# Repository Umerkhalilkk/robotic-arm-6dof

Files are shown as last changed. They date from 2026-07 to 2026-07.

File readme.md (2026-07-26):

# Robotic Arm (6 DOF)

A robotic arm controlled through a smaller, hand-built master arm. Potentiometers on the master arm sense joint position, and a microcontroller maps those readings to servo positions on the main arm, so moving a joint on the small arm moves the corresponding joint on the large arm in real time.

## Photos

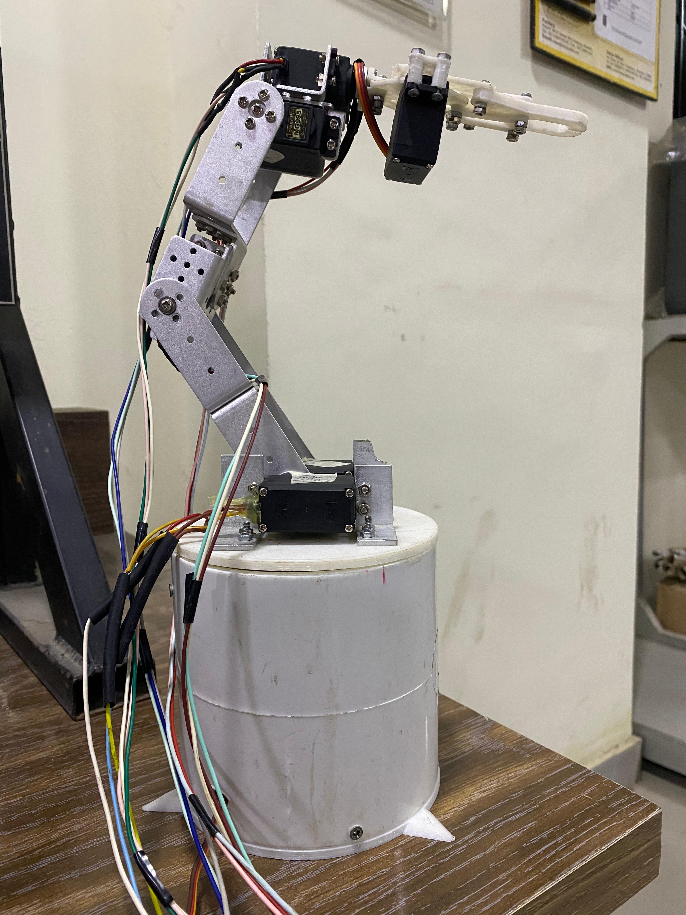
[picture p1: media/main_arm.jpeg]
Main robotic arm
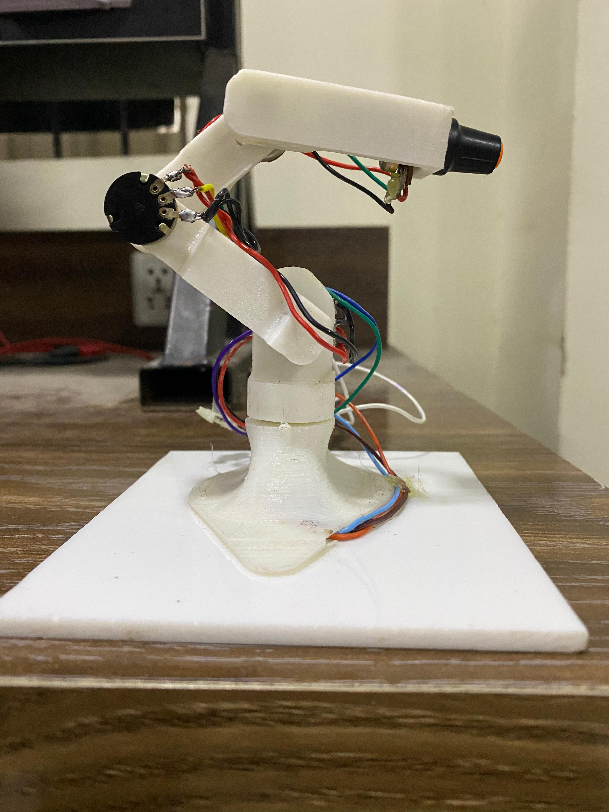
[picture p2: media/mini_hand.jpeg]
Master arm (mini hand)
 

*Left: the main 6 DOF robotic arm. Right: the master arm used to control it.*

## Team

- [Muhammad Aqib Shabbir](https://github.com/maqibshabbir)
- Muhammad Umer
- Areesh e Mustafa

## Overview

The system consists of two physical arms and one control board.

**Main arm** — the arm being controlled. The base was built around a custom PCB, with the base structure (bottom, middle, top) and body designed and modeled by the team in SolidWorks. The gripper mechanism uses an existing open-source design, adapted and 3D printed in PLA. The arm is driven by seven servo motors.

**Master arm (mini hand)** — the input device, also designed and built by the team. It uses five potentiometers to represent five of the main arm's joints, plus one push button to control the gripper (open/close).

**Control board** — an Arduino Uno reads the potentiometer and button states, maps them to servo angles, and drives the main arm's servos accordingly. A custom PCB was designed and etched at home to host the electronics, and the system is powered from a computer power supply rather than batteries.

## How it works

```
Potentiometer / Button (master arm) → Arduino Uno → Servo Motors (main arm)
```

1. Each potentiometer on the master arm outputs an analog voltage corresponding to its joint's position.
2. The Arduino reads these values and maps them from the 0–1023 ADC range to a 0–180 degree servo range.
3. The mapped angle is written to the matching servo on the main arm.
4. The push button toggles the gripper servo between open and closed positions.
5. Joint values are also printed to the Serial Monitor for live monitoring.

### Smoothing servo jitter

During testing, the servos exhibited jerky, unstable movement. An oscilloscope was used to inspect the PWM control signal directly, which helped identify the source of the instability and guided the changes made to smooth out motion. This hardware-level verification is what separated debugging this build from a purely code-side fix.

## Repository structure

```
cad/
  main_arm/
    arm-base/              Base structure — bottom, middle, top, and main parts
    arm-body/               Arm body and servo/horn components
    arm-full-assembly/      Full main arm assembly
    arm-gripper/            Gripper design (third-party, see Credits) and assembly
  mini_hand/
    arm-full-assembly/      Full master arm assembly
    arm-full-body/          Master arm links and base

docs/
  robotic_arm_6dof_technical_report.pdf   Full project report

firmware/
  arm_controller.ino        Arduino firmware

media/
  main_arm.jpeg              Photo of the completed main arm
  mini_hand.jpeg              Photo of the completed master arm

models/
  main_arm.stl               Interactive 3D model of the main arm
  mini_arm.stl                Interactive 3D model of the master arm

pcb/
  arm_pcb_print.pdf          PCB layout used for home etching
  pcb_front.jpg               Photo of the built PCB, front
  pcb_back.jpg                Photo of the built PCB, back
```

## 3D Models

Both arms can be viewed and rotated directly in the browser using GitHub's built-in 3D viewer — no software download required. Click a link below, then click-drag to rotate and scroll to zoom.

- [Main Arm — main_arm.stl](models/main_arm.stl)
- [Mini Hand — mini_arm.stl](models/mini_arm.stl)

## Hardware

- Microcontroller: Arduino Uno
- 7x servo motor (main arm joints and gripper)
- 5x potentiometer (master arm joint sensing)
- 1x push button (gripper control)
- Custom PCB (etched at home from the layout in `pcb/arm_pcb_print.pdf`)
- Power: computer power supply unit
- 3D printed gripper (PLA)
- Base: custom PCB-integrated structure, with bottom/middle/top sections modeled in SolidWorks

## Software tools used

- SolidWorks — CAD modeling of the base, body, and master arm
- Arduino IDE — firmware
- Proteus — schematic and PCB design assistance
- Oscilloscope — signal-level debugging of servo control lines

## Getting started

1. Open `firmware/arm_controller.ino` in the Arduino IDE.
2. Wire the potentiometers and servos according to the pin definitions at the top of the code.
3. Upload the firmware to the Arduino Uno.
4. Power the board using a regulated supply matching the servo current requirements.
5. Open the Serial Monitor (9600 baud) to view live joint values while testing.

## Results

The arm reliably mirrored the master arm's movements, with the gripper responding correctly to the push button. Oscilloscope-guided debugging resolved early jitter issues, producing smooth, consistent motion. Full details, results, and discussion are documented in the project report: [`docs/robotic_arm_6dof_technical_report.pdf`](docs/robotic_arm_6dof_technical_report.pdf)

## Credits

- Gripper CAD design: third-party design, adapted for this build (source to be added)
- PCB layout assistance: Engr. Zaryab Qazi

## License

This project is released under the MIT License. See [`LICENSE`](LICENSE) for details.

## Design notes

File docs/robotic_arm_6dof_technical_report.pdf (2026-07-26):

# ENGINEERING WORKSHOP

## Project Title:

## Robotic Arm (6 DOF)

## Submitted to:

## Zaryab Qazi

## Submitted by:

## - Muhammad Aqib Shabbir

## - Muhammad Umer

## - Areesh e Mustafa

## Table of Contents

### 1. ABSTRACT:

This project presents the design and development of a 6 Degrees of Freedom (DOF)

robotic arm controlled by a miniature robotic arm with integrated potentiometers for

position feedback. The system is designed to simulate and replicate the movements

of the main robotic arm based on the inputs received from the mini arm, enabling

precise control and manipulation. The main robotic arm is modeled in SolidWorks,

allowing for detailed mechanical design and motion analysis. Potentiometers

attached to the mini arm measure joint angles and provide real-time feedback to a

microcontroller, which processes the data to control the movement of the main arm.

The project integrates hardware components, including motors, sensors, and

microcontrollers, with software algorithms for calculations and motion control. The

result is a functional, interactive robotic system capable of replicating the movements

of the mini arm, offering valuable insights into the fields of robotics, control systems, and automation. This design can serve as a foundation for more advanced

applications in robotic manipulation and automation tasks.

## 2. INTRODUCTION:

Robotic arms have become a cornerstone of automation and precision tasks across

various industries, including manufacturing, healthcare, and research. The ability to

control the position and movement of these arms with high accuracy and flexibility

is crucial for achieving complex operations. This project focuses on the design and

development of a 6 Degrees of Freedom (DOF) robotic arm that is controlled using

a miniature robotic arm equipped with potentiometers for precise joint position

feedback. The mini arm acts as a control interface, where the movement of its joints

is sensed and translated into corresponding actions in the main robotic arm.

The main robotic arm, designed and modeled using SolidWorks, consists of six

independently controlled joints, allowing for a wide range of motion and flexibility.

Each joint is connected to a motor, with feedback from potentiometers attached to

the mini arm’s joints providing real-time positional data. This data is processed by a

microcontroller to calculate the necessary movements for the main arm, ensuring

accurate replication of the mini arm’s movements.

This project combines mechanical engineering, control systems, and electronics to

create an interactive robotic arm. The control system, using a microcontroller and

potentiometer feedback, maps the motion of a mini arm to the main arm, enabling

precise manipulation. The goal is to demonstrate a system that mimics the movement

of the smaller arm with high accuracy, offering insights for future robotics research

and applications. This design can be adapted for various robotic tasks, enhancing the

control and manipulation of multi-jointed robotic systems.

## 3. SOFTWARE TOOLS

The following software tools are commonly used in the design, and control of robotic

systems like the one described in this

- SolidWorks: Used for 3D modeling and design of the robotic arm, including

the main arm, joints, and mini arm. SolidWorks also enables motion simulations and interference checks. CAD design, motion simulation,

assembly design, kinematic analysis.

- Arduino IDE: The primary environment for programming the

microcontroller (such as Arduino or ESP32) that controls the robotic arm.

C/C++ programming, serial communication, support for sensors and

actuators, integration with external libraries for controlling motors and

reading potentiometer values.

- Proteus: Proteus supports simulation of microcontrollers, so you can write

the control code (e.g., Arduino code) in the Arduino IDE, then upload it to

the Proteus simulation for testing. PCB design, schematic capture, and layout.

The PCB design for this project was created with the assistance of Engr.

Zaryab Quazi, who provided valuable expertise in the design and layout of

the circuit board.

## 4. FLOW CHART

## 5. CODE

#include <Servo.h>

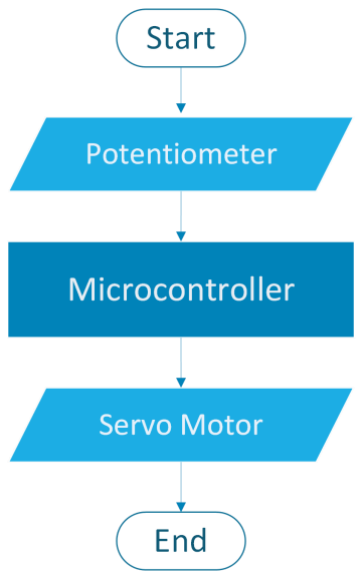
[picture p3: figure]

Servo servo1; const int
servo1PotPin =A0; const
int servo1Pin = 7; int
servo1Value; Servo servo2; const int servo2PotPin =A1; const int servo2Pin = 6;
int servo2Value; Servo
servo3; const int
servo3PotPin =A2; const int servo3Pin = 5; int
servo3Value; Servo servo4; const int servo4PotPin =A3; const int servo4Pin = 3;
int servo4Value; Servo
servo5; const int
servo5PotPin =A4; const int servo5Pin = 4; int
servo5Value;
Servo servo6;
const int servo6buttonPin =13; const int servo6Pin = 2; int pushButton; void setup() { Serial.begin(9600);
servo1.attach(servo1Pin);
servo2.attach(servo2Pin);
servo3.attach(servo3Pin);
servo4.attach(servo4Pin);
servo5.attach(servo5Pin);
servo6.attach(servo6Pin);
} void loop() { | servo1Value =
analogRead(servo1PotPin); | servo1Value =
map(servo1Value, 1023, 0, 0, 180); servo1.write(servo1Value); Serial.print(servo1Value);
servo2Value = analogRead(servo2PotPin); servo2Value = map(servo2Value, 0, 1023, 0, 180); servo2.write(servo2Value);
Serial.print(" ");Serial.print(servo2Value); servo3Value = analogRead(servo3PotPin); servo3Value = map(servo3Value, 0, 1023, 0, 180); servo3.write(servo3Value);
Serial.print(" ");Serial.print(servo3Value); servo4Value = analogRead(servo4PotPin); servo4Value = map(servo4Value, 0, 1023, 0, 180); servo4.write(servo4Value);
Serial.print(" ");Serial.print(servo4Value); servo5Value = analogRead(servo5PotPin); servo5Value = map(servo5Value, 0, 1023, 0, 180); servo5.write(servo5Value);

Serial.print(" ");Serial.print(servo5Value);

pushButton=digitalRead(servo6buttonPin); if(pushButton==LOW)
{
servo6.write(0);
Serial.print(" ");Serial.print("Close"); }
else
{
servo6.write(45);
Serial.print(" ");Serial.println("Open"); }
delay(5);
}

## 6. WORKING

The robotic arm operates through the input of six control elements: five

potentiometers and a push button. These control elements are used to monitor and

adjust the position of the arm's joints. Each potentiometer is connected to a specific

joint on the mini robotic arm and acts as a position sensor, determining the angle of

the joint. When the mini arm moves, the corresponding potentiometer detects the

change in joint position by varying its resistance. This change in resistance is

converted into an analog voltage, which is then sent to the microcontroller for

processing.

The microcontroller reads the analog values from the potentiometers via the Analog

Read Pins. Since the potentiometer’s output ranges from 0 to 1023, corresponding to

the full range of motion (0 to 180 degrees) of the servo motors, the microcontroller

maps these values to a servo-friendly range using the map() function. This function

adjusts the range of values from (0-1023) into a 0–180-degree range, which is the

operational range for standard servos.

Once the potentiometer values are mapped to a degree range, the microcontroller

sends the corresponding signals to the servo motors, which adjust the position of the

joints in the main robotic arm.

The robotic arm includes a push button that controls the sixth servo, which might

represent a gripper or similar mechanism. This push button is connected to a digital

input pin of the microcontroller. The button has two possible states: pressed (LOW)

or released (HIGH). When the button is pressed (LOW state), the sixth servo moves

to the "closed" position, which could mean the gripper closes. When the button is

released (HIGH state), the sixth servo moves to the "open" position, causing the

gripper to open. This allows for manual control of a specific function, such as

gripping or releasing objects.

The serial monitor displays the potentiometer values in real-time, providing feedback

on each joint's angle as the potentiometers are adjusted. This helps the user track the

arm's movements and troubleshoot if necessary. A 5-millisecond delay in the loop()

function ensures smooth and controlled motion, preventing the servos from moving

too quickly and causing instability.

In summary, the system reads potentiometer inputs to control the servo motors of the

main robotic arm, with the push button controlling a sixth servo (e.g., a gripper). The

serial monitor provides real-time feedback, offering an intuitive way to control the

robotic arm based on the mini arm's movements.

## 7. RESULT AND DISCUSSIONS

The 6-DOF robotic arm operated as expected, with the potentiometers providing

accurate control over the arm's movements. Each joint's position was directly linked

to its corresponding potentiometer, with smooth and responsive servo motion. The

push button effectively controlled the 6th servo, allowing for simple gripper

functionality, toggling between "open" and "closed" positions.

The 5-millisecond delay in the loop() function ensured smooth motion and prevented

jittery movements by slowing down the servo response. The real-time feedback on

the serial monitor helped track the arm’s performance, providing useful data for

troubleshooting.

Overall, the system performed well with precise and synchronized movement

between the mini and main robotic arms. Potential improvements include fine-tuning

the servo precision, adding advanced control algorithms, and incorporating

additional sensors for enhanced functionality.

## 8. CONCLUSION

The 6-DOF robotic arm, controlled by potentiometers and a push button, successfully

demonstrated the ability to replicate the motion of a mini robotic arm. The system operated smoothly, with the potentiometers providing precise control over each joint,

and the push button enabling simple control of the 6th servo (e.g., for gripper

function). The use of a delay ensured stable movement, and the serial monitor

provided real-time feedback for monitoring and debugging.

This project highlights the potential for using basic sensors and simple control

systems to operate complex robotic systems. Future improvements could involve

refining the control algorithms and adding more sensors for enhanced precision and

functionality. Overall, the project serves as a solid foundation for further exploration

and development in robotic control systems.

## 9. PROJECT SUMMARY

This project involves the design and implementation of a 6-DOF robotic arm

controlled by a mini arm equipped with potentiometers and a push button. The

potentiometers detect the angle of each joint on the mini arm, and their corresponding

values are sent to a microcontroller, which processes these inputs to control the

movement of the main robotic arm. The push button controls a 6th servo, such as a

gripper, allowing for simple open/close functionality. The system operates smoothly,

with real-time feedback displayed on the serial monitor for monitoring the arm's

movements. A delay is included in the control loop to ensure stable motion and avoid

erratic servo movements. This project demonstrates the use of basic sensors and

control systems to create a functional and responsive robotic arm, offering a

foundation for further development in robotic automation.

### 10. REFERENCES

Arduino. (n.d.). Arduino Documentation. Retrieved December 26, 2024, from

https://www.arduino.cc/

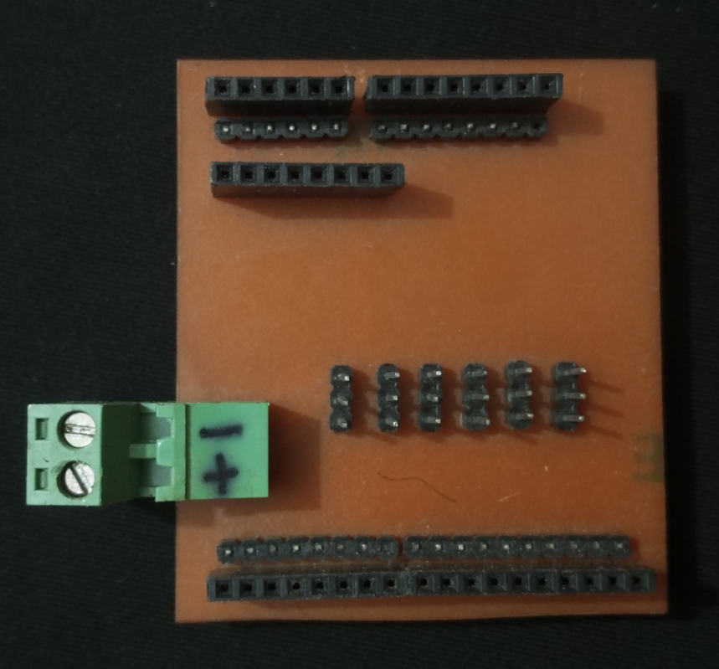
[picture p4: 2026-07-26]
pcb/pcb_front.jpg.jpeg

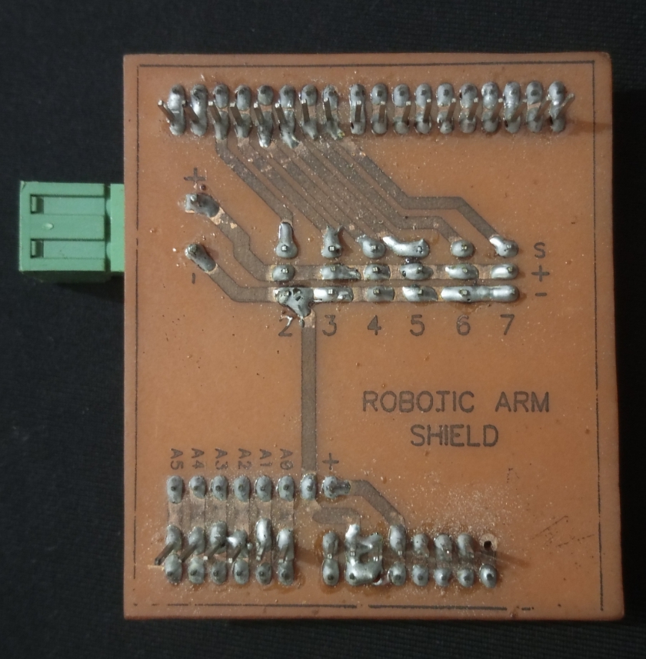
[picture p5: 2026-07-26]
pcb/pcb_back.jpg.jpeg

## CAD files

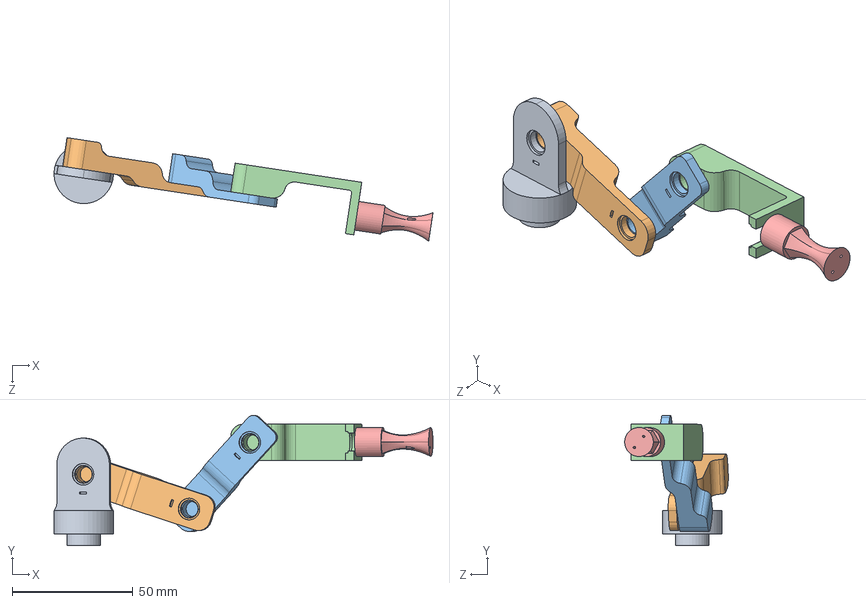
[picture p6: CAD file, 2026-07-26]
cad/mini_hand/arm-full-assembly/Assem1.SLDASM
156.8 x 53.9 x 42.9 mm
base
link 1
link 2
link 3
rotatory link

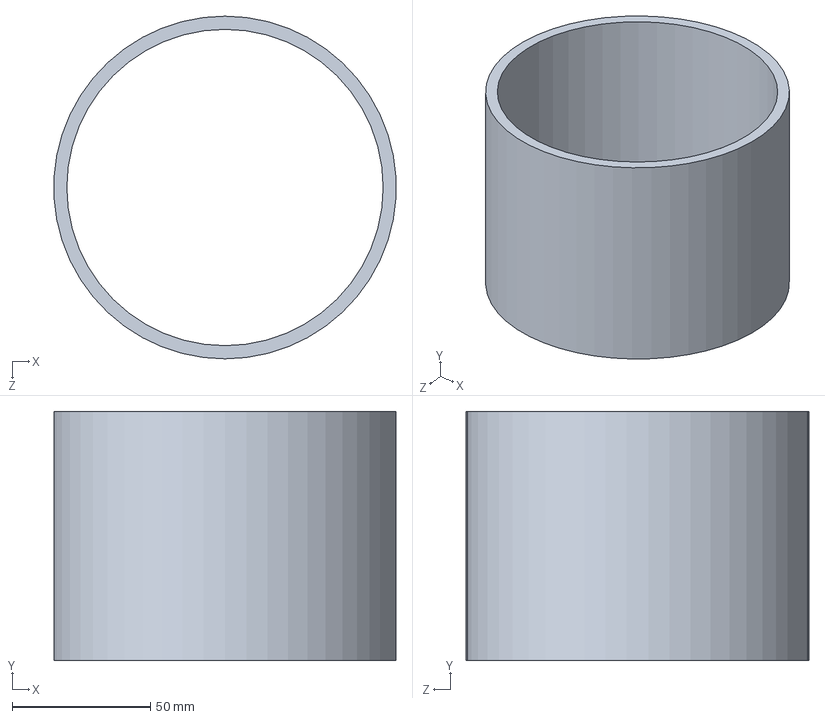
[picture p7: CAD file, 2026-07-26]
cad/main_arm/arm-base/main.SLDPRT
123.6 x 90.0 x 123.8 mm

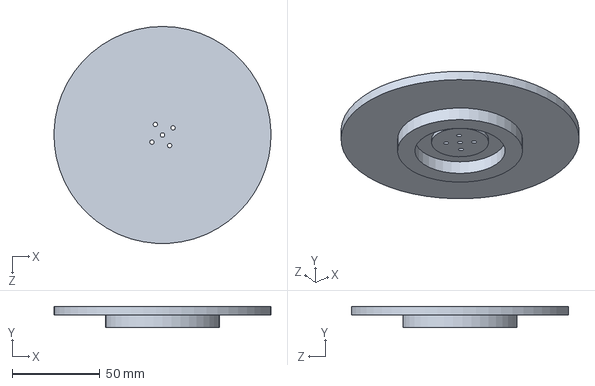
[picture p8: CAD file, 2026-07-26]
cad/main_arm/arm-base/top.SLDPRT
123.8 x 12.0 x 123.8 mm

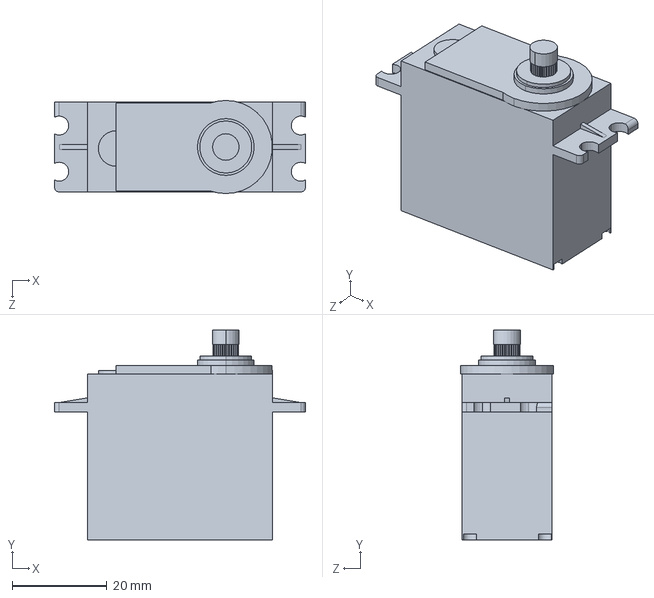
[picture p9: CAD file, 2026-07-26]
cad/main_arm/arm-body/macro-servo2.SLDPRT
53.0 x 44.3 x 19.7 mm

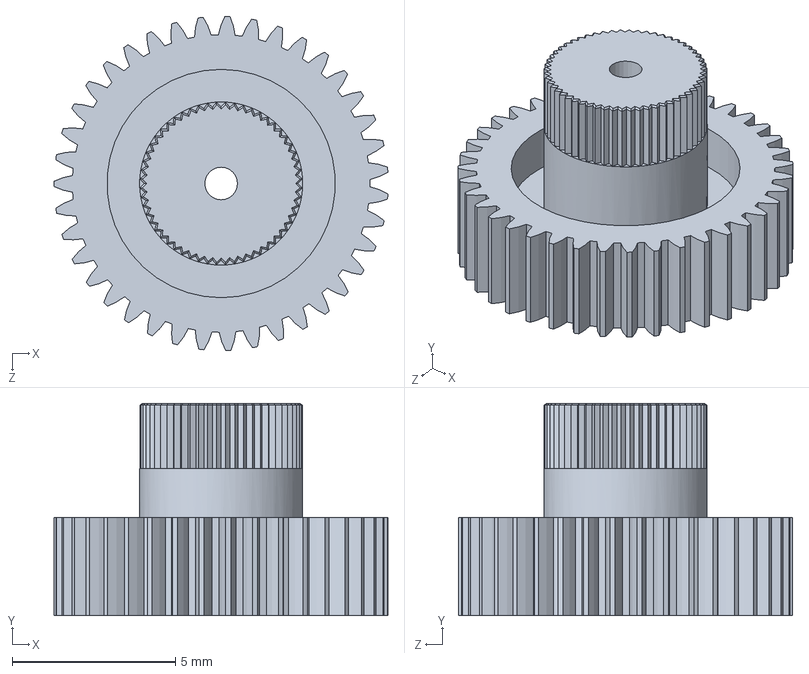
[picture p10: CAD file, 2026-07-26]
cad/main_arm/arm-gripper/4.SLDPRT
10.2 x 6.50 x 10.2 mm

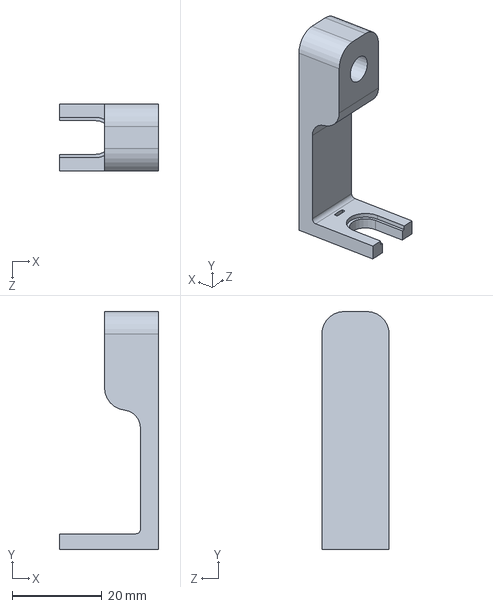
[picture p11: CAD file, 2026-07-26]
cad/mini_hand/arm-full-body/link 3.SLDPRT
22.0 x 53.0 x 15.0 mm

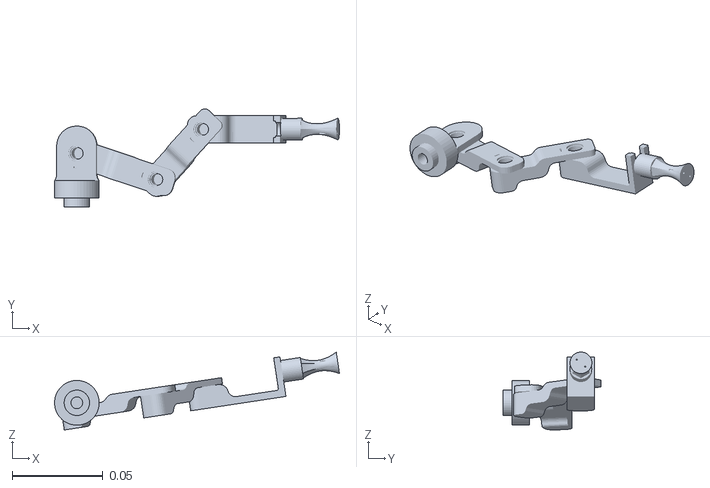
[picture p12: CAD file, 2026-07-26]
models/mini_arm.stl
0.157 x 0.0539 x 0.0429

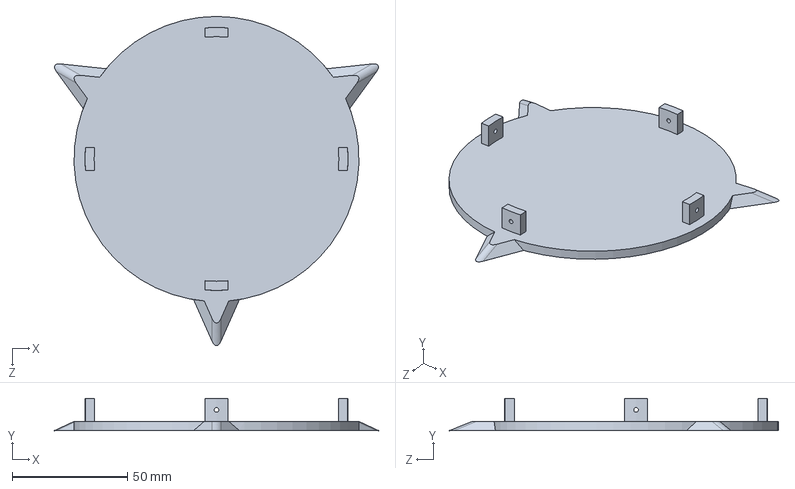
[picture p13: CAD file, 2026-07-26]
cad/main_arm/arm-base/bottom.SLDPRT
140.8 x 14.0 x 143.0 mm

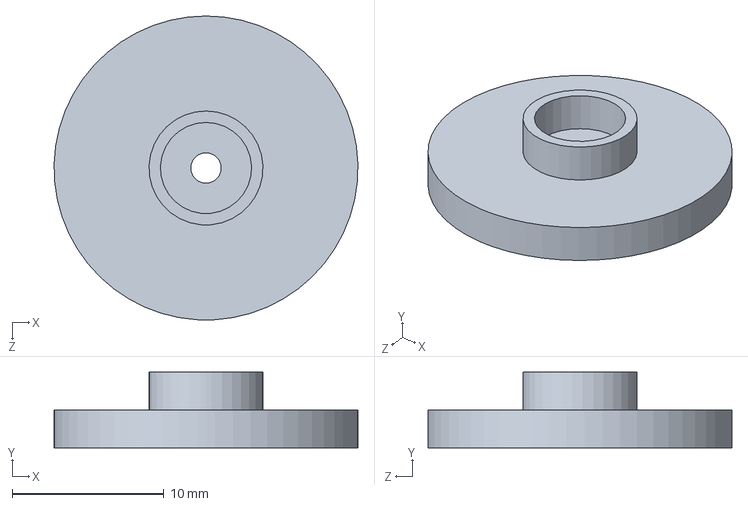
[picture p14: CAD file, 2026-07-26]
cad/main_arm/arm-body/servo horn.SLDPRT
20.0 x 5.00 x 20.0 mm

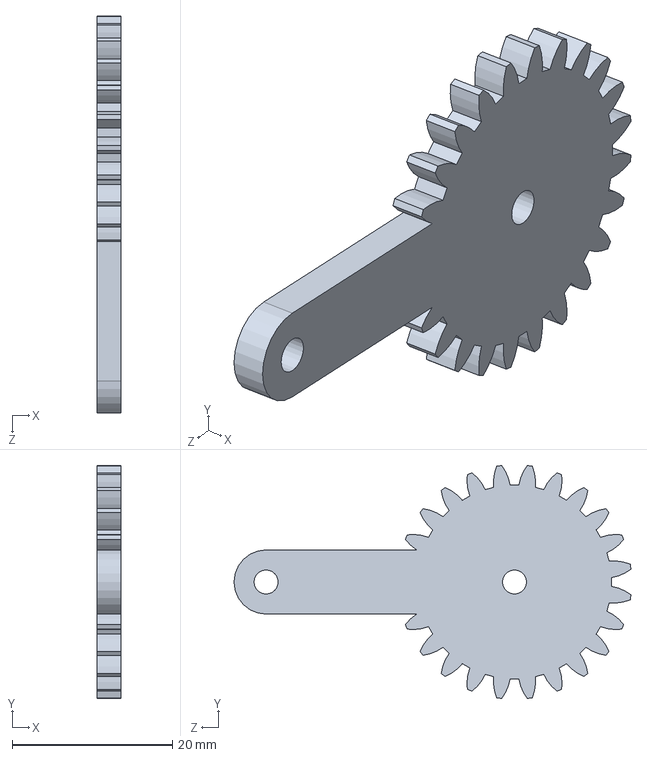
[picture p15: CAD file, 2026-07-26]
cad/main_arm/arm-gripper/4.1.SLDPRT
3.00 x 29.1 x 49.5 mm

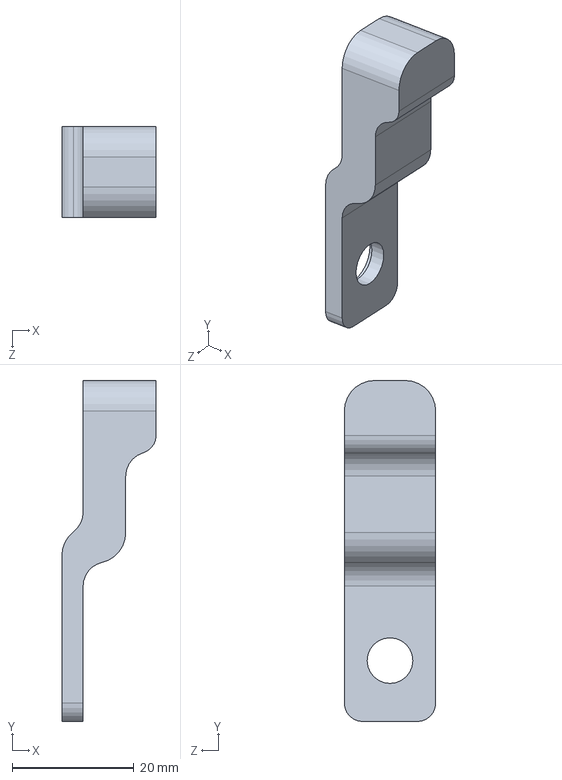
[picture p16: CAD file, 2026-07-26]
cad/mini_hand/arm-full-body/link 2.SLDPRT
15.5 x 56.0 x 15.0 mm

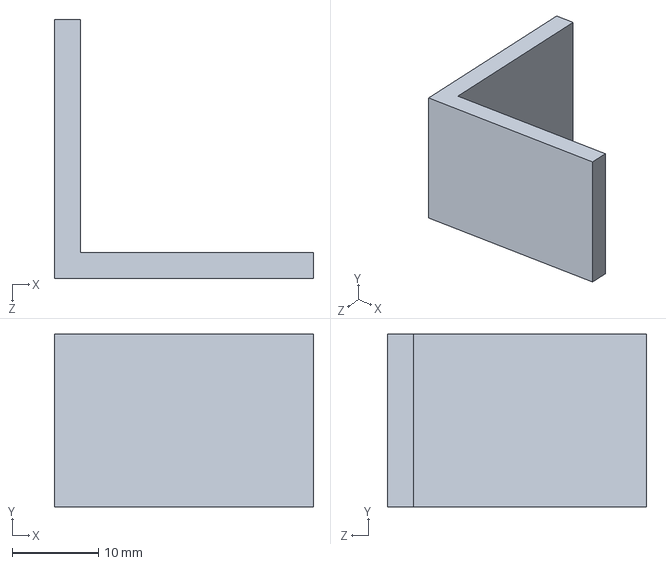
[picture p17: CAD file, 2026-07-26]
cad/main_arm/arm-body/Part3.SLDPRT
30.0 x 20.0 x 30.0 mm

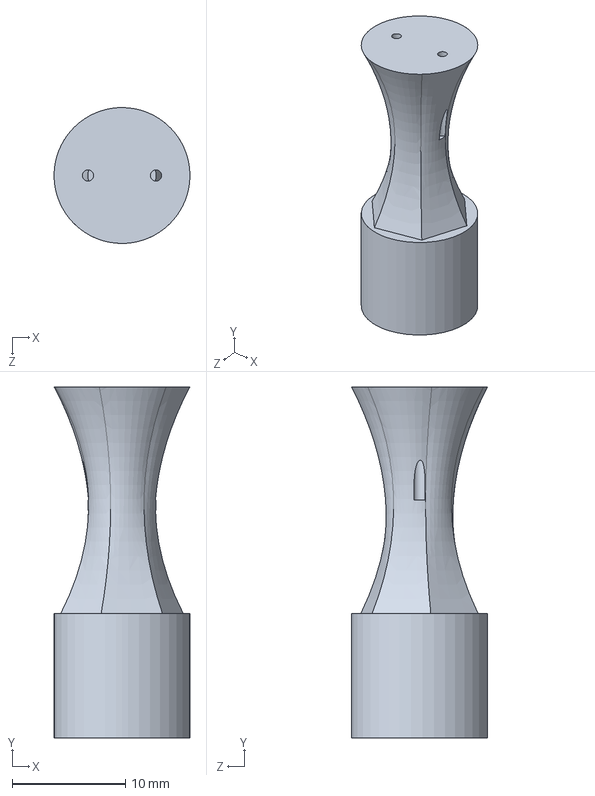
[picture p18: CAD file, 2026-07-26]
cad/mini_hand/arm-full-body/rotatory link.SLDPRT
12.0 x 31.0 x 12.0 mm

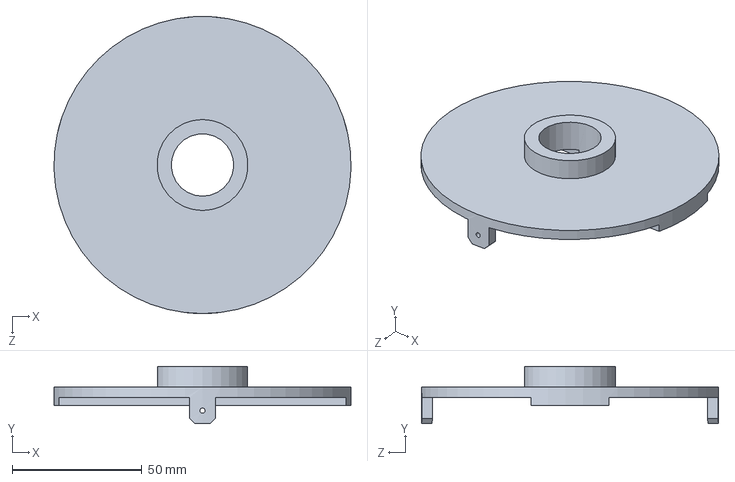
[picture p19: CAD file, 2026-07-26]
cad/main_arm/arm-base/middle.SLDPRT
114.2 x 22.0 x 114.3 mm

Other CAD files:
cad/main_arm/arm-full-assembly/robot.SLDASM
cad/main_arm/arm-gripper/Assem1.SLDASM
cad/main_arm/arm-body/Part.SLDPRT
cad/main_arm/arm-gripper/7.SLDPRT
cad/main_arm/arm-body/Part1.SLDPRT
cad/main_arm/arm-gripper/1.SLDPRT
cad/main_arm/arm-gripper/2.SLDPRT
cad/main_arm/arm-gripper/3.SLDPRT
cad/main_arm/arm-gripper/5.SLDPRT
cad/main_arm/arm-gripper/8.SLDPRT
cad/main_arm/arm-gripper/Part6_pin.SLDPRT
cad/mini_hand/arm-full-body/base.SLDPRT
cad/mini_hand/arm-full-body/link 1.SLDPRT

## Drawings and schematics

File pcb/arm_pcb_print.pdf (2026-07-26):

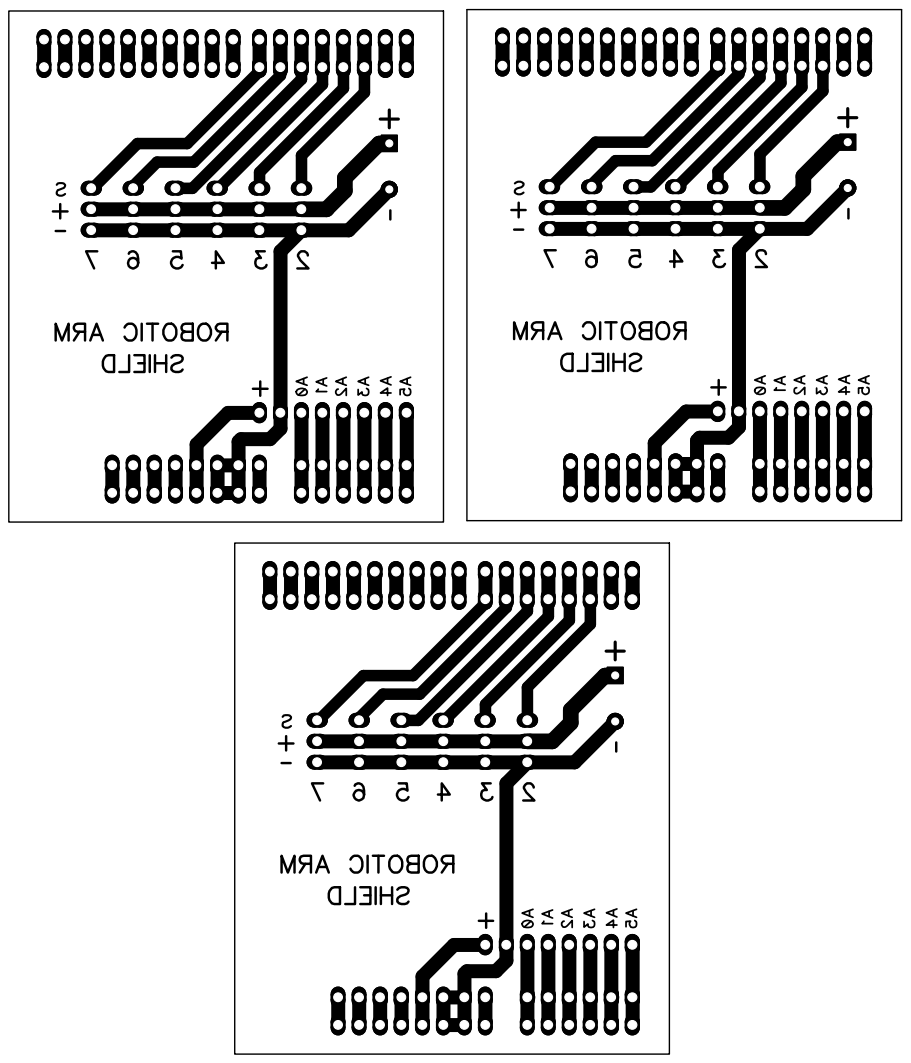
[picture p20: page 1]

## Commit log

2026-07-26 Initial commit: robotic arm 6DOF project
    [1.SLDPRT, 2.SLDPRT, 3.SLDPRT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]
2026-07-26 Add 3D viewable models of main arm and mini hand
    [mini_arm.stl]
